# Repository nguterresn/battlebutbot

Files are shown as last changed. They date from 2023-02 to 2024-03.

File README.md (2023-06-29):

# BattleButBot: Your Ultimate Antweight Fighting Robot Companion

BattleButBot is a small and powerful robot designed specifically for the Antweight class of robot combat events. With its sleek design, sturdy construction, and advanced control features, BattleButBot is the perfect choice for robot fighting enthusiasts of all skill levels.

## Features

- **Intuitive Web-based Control**: BattleButBot can be easily controlled from any device with a web browser, allowing you to take full control of your robot in real-time.
- **Powerful Motors**: BattleButBot's high-torque motors provide superior performance and speed, allowing your robot to deliver powerful punches and moves.
- **Durable Build**: BattleButBot is built to withstand the toughest battles in Antweight robot combat events. Its rugged construction and impact-resistant design ensure that your robot stays in one piece, no matter how intense the fight gets.
- **Customizable Weapons**: BattleButBot's weapons can be customized to suit your fighting style. With a range of weapons and attachments available, you can build your robot to be the ultimate fighting machine.
- **Easy to Use**: BattleButBot is easy to use and requires no special skills or training. With its intuitive controls and simple setup process, you can start battling right away.

## Clone

Clone the project by running the following command:

```bash
git clone --recurse-submodules -j8 git@github.com:nguterresn/battlebutbot.git
```

The option `-j8` will allow the command to download up to 8 sumodules in parallel. 

## Goal

* Design the skeleton of the battle bot and list all the required hardware components.
* Assemble the battle bot by mounting all the necessary parts.
* Compete in battles to test the performance of the battle bot.
* Iterate and improve the design based on the performance results.
* Profit from your successful battle bot design.

## List of requirements

* **Cheap**: Priced under $50/500kr
* **Weight**: Weighs less than 150 milligrams
* **Acessable**: All parts are easily available
* **Flexible**: Can be controlled over WiFi or using an RF controller
* **Simple**: All hardware components are easy to assemble
* **Portable**: Powered by a lithium battery

## List of hardware:

| Hardware | Qty | Price |
|---|-----|---|
| [N20 Gear Motor 6V 600RPM](https://www.aliexpress.com/item/1005003480074662.html?spm=a2g0o.cart.0.0.66f238dazFIII7&mp=1) | 2 | 90kr  |
| [DollaTek 5PCS DRV8833 1.5A 2-Channel DC Motor Drive Board](https://www.amazon.se/DollaTek-drivbräda-ultra-liten-drivmodul-ingångsspänning/dp/B07ML2RDNY/ref=sr_1_1?crid=39VO6618PX6XD&keywords=DRV8833&qid=1667334481&qu=eyJxc2MiOiIyLjI4IiwicXNhIjoiMS43NiIsInFzcCI6IjAuOTIifQ%3D%3D&sprefix=drv8833%2Caps%2C115&sr=8-1) | 1 | 17kr  |
| [Wemos D1 Mini ESP8266](https://www.amazon.se/-/en/dp/B01N9RXGHY/ref=twister_B08BY192W7?_encoding=UTF8&psc=1) | 1 | 87kr  |

## Pinout

pinout-diagram

## How to open the GUI

Connect using WiFi to `BattleButBot`.



Open `bot.local` on you browser.



## About the GUI

To control BattleButBot, simply use the **joystick** located in the center of the screen. To configure your joystick settings, click the `⚙️ Config` button.

You can monitor your robot's speed with the speed meter located above the joystick, which displays your robot's speed in meters per second.

Although the **action** button is currently inactive, it will be available in the near future.

For ease of development while the robot firmware is unstable or in development, a console log is located at the bottom of the screen. In the future, an option will be added to hide this log.

## Robot Controls

You can control BattleButBot using the joystick on the graphical user interface (GUI). To move forward, drag the joystick upwards, and to move backward, drag the joystick downwards. The joystick works on an X and Y axis, with Y controlling the speed of the robot and X controlling the direction of movement (left or right).

## Technical Details

(TBA)

## 3rd Party Libraries

- [ESPAsyncWebServer](https://github.com/me-no-dev/ESPAsyncWebServer)
- [Joystick 2](https://github.com/bobboteck/JoyStick)
- [CSS Skeleton Framework](https://skeleton-framework.github.io)

## Tools

- VSCode with PlatformIO
- Fusion360

## Support

If you have any questions or issues with BattleButBot, please contact guterresnogueira@gmail.com. We're always here to help you get the most out of your robot.

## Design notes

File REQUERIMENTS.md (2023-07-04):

This is enough to validate the product and to finish the MVP.

- [ ] Fully 3D printed robot (everything)
  - [ ] PLA/PETG Body
  - [ ] TPU Wheels
- [ ] Easily accessible parts (everyone can buy online)
  - [ ] Battery
  - [ ] Main Controller
  - [ ] Main Driver
  - [ ] Servo
  - [ ] Extra Sensors
- [ ] Option to include a PCB or not (usable with a breadboard as well)
  - [ ] A PCB Requires other modules, makes the robot smarter and ready to battle.
  - [ ] The breadboard option is for development and not meant to be used in battles.
- [ ] Sturdy enclosure (protect around the battery and other electrical components)
- [ ] No need for controller (user can use the phone) but we provide a controller option that is better and ideal for battling.
  - [ ] Phone controller on web (Android or iOS)
  - [ ] RF External Controller (Previous requirements also apply)

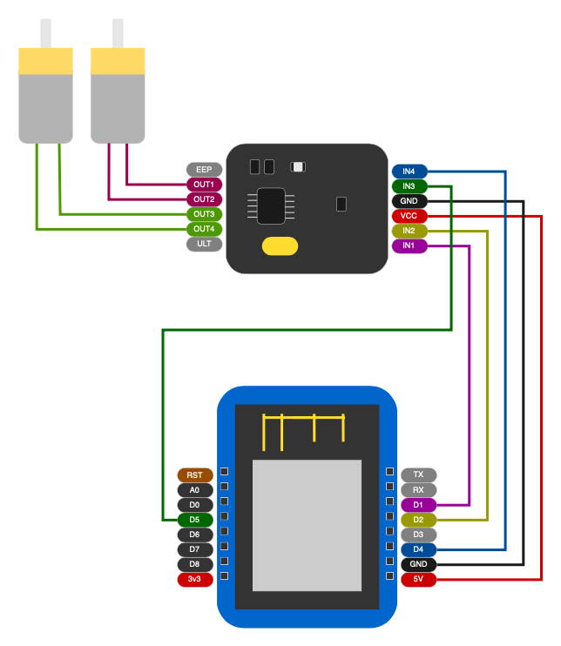
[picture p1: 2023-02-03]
docs/pinout/pinout-diagram.png

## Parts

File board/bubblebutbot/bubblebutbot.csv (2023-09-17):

Comment | Designator | Footprint | LCSC
Buzzer | BZ1 | Buzzer_Beeper:MagneticBuzzer_PUI_AT-0927-TT-6-R | C96256
10u | C1,C2,C3,C9,C10 | Capacitor_SMD:C_0603_1608Metric_Pad1.08x0.95mm_HandSolder | C380316
22u | C12 | Capacitor_SMD:C_1206_3216Metric_Pad1.33x1.80mm_HandSolder | C12891
1u | C4,C5 | Capacitor_SMD:C_0603_1608Metric_Pad1.08x0.95mm_HandSolder | C1592
100n | C6,C8,C11 | Capacitor_SMD:C_0603_1608Metric_Pad1.08x0.95mm_HandSolder | C282519
2.2u | C7 | Capacitor_SMD:C_0603_1608Metric_Pad1.08x0.95mm_HandSolder | C2691406
LED | D1,D3 | LED_SMD:LED_0603_1608Metric_Pad1.05x0.95mm_HandSolder | C965799
SS14 | D2 | Diode_SMD:D_SMA | C2480
MountingHole | H1,H2 | MountingHole:MountingHole_3.2mm_M3_ISO14580_Pad
JST XH | J1,J9,J10,J11,J13 | Connector_JST:JST_PH_S2B-PH-K_1x02_P2.00mm_Horizontal | C722769
USB_C_Receptacle | J2 | Connector_USB:USB_C_Receptacle_GCT_USB4105-xx-A_16P_TopMnt_Horizontal | C2765186
Conn_01x03_Socket | J3,J4,J5,J6,J7,J8 | Connector_JST:JST_PH_S3B-PH-K_1x03_P2.00mm_Horizontal | C10400
4.7u | L1 | Inductor_SMD:L_Wuerth_WE-TPC-3816 | C2879693
FDN336P | Q1 | Package_TO_SOT_SMD:SOT-23 | C475693
5.1K | R1,R2,R3,R4,R6,R7,R9,R10,R12,R13,R17 | Resistor_SMD:R_0603_1608Metric_Pad0.98x0.95mm_HandSolder | C2907114
50k | R11 | Resistor_SMD:R_0603_1608Metric_Pad0.98x0.95mm_HandSolder | C304067
R | R16 | Resistor_SMD:R_0603_1608Metric_Pad0.98x0.95mm_HandSolder | C2930064
3.3k | R5 | Resistor_SMD:R_0603_1608Metric_Pad0.98x0.95mm_HandSolder | C3017726
100k | R8,R14,R15 | Resistor_SMD:R_0603_1608Metric_Pad0.98x0.95mm_HandSolder | C2907088
SW_Push | SW1,SW2 | Button_Switch_SMD:SW_SPST_B3U-1000P | C455280
SW_DIP_x04 | SW3 | Button_Switch_THT:SW_DIP_SPSTx04_Piano_10.8x11.72mm_W7.62mm_P2.54mm | C99418
DRV8833PWP | U1 | Package_SO:HTSSOP-16-1EP_4.4x5mm_P0.65mm_EP3.4x5mm_Mask2.46x2.31mm_ThermalVias | C50506
ESP32-S3-WROOM-1 | U2 | RF_Module:ESP32-S3-WROOM-1 | C2913198
AP2112K-3.3 | U3 | Package_TO_SOT_SMD:SOT-23-5 | C51118
LIS3DH | U4 | Package_LGA:LGA-16_3x3mm_P0.5mm_LayoutBorder3x5y | C15134
~ | U5 | Package_TO_SOT_SMD:SOT-23-8 | C2937216

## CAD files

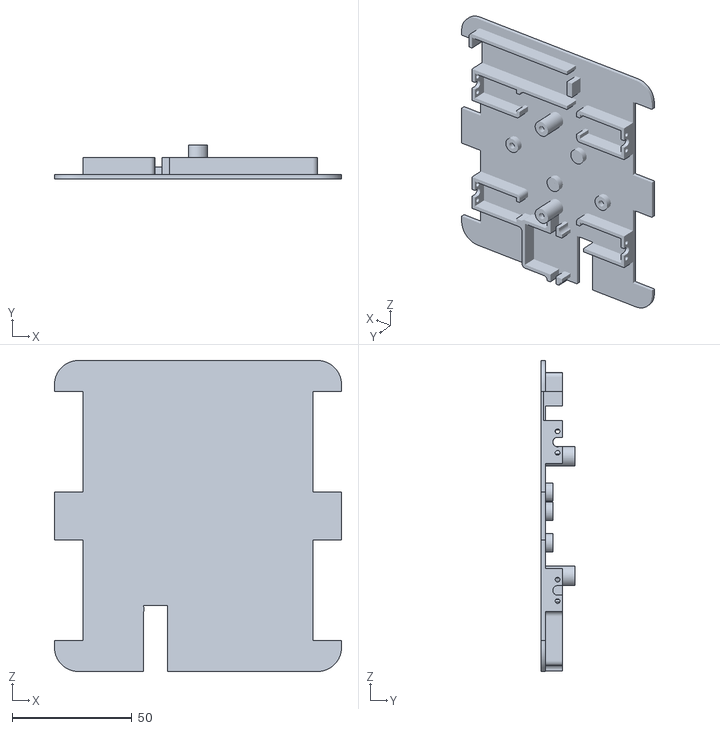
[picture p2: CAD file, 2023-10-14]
board/bubblebutbot/bottom.stl
120.0 x 14.3 x 130.0

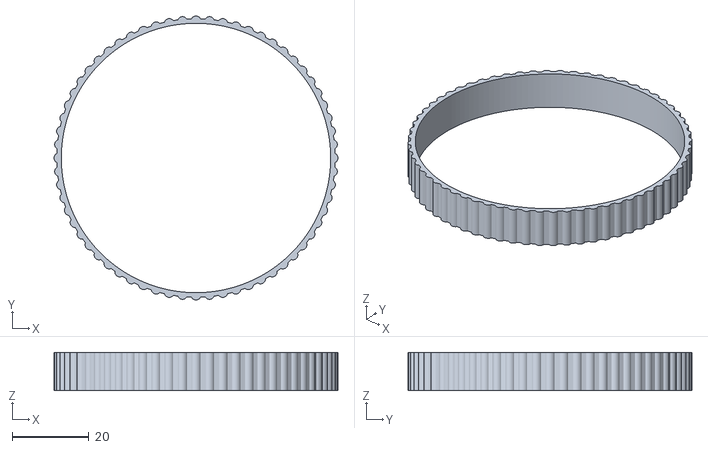
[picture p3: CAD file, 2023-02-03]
body/gustaf/ribbed-belt_v1.stl
73.8 x 73.8 x 10.0

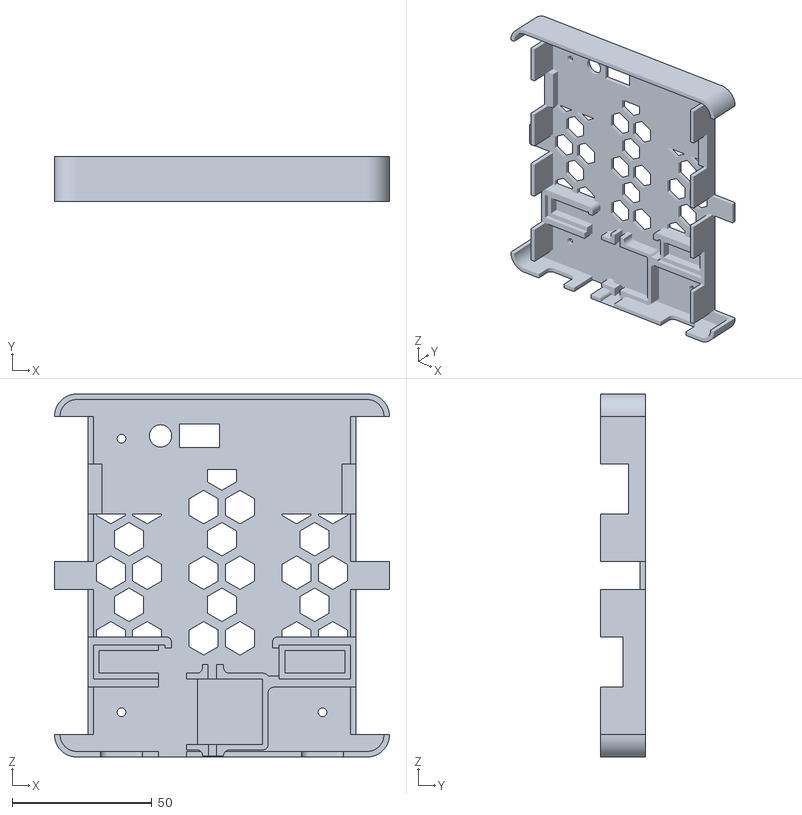
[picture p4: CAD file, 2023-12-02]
body/prod/top.stl
120.0 x 16.0 x 130.0

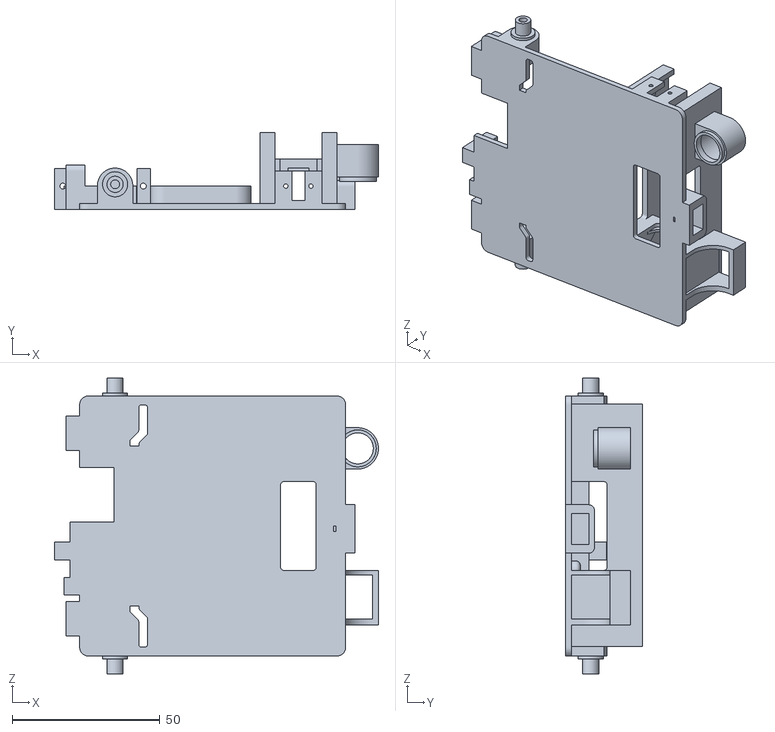
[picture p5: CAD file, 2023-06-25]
body/prototype/Car_with_extras.stl
109.6 x 26.0 x 100.0

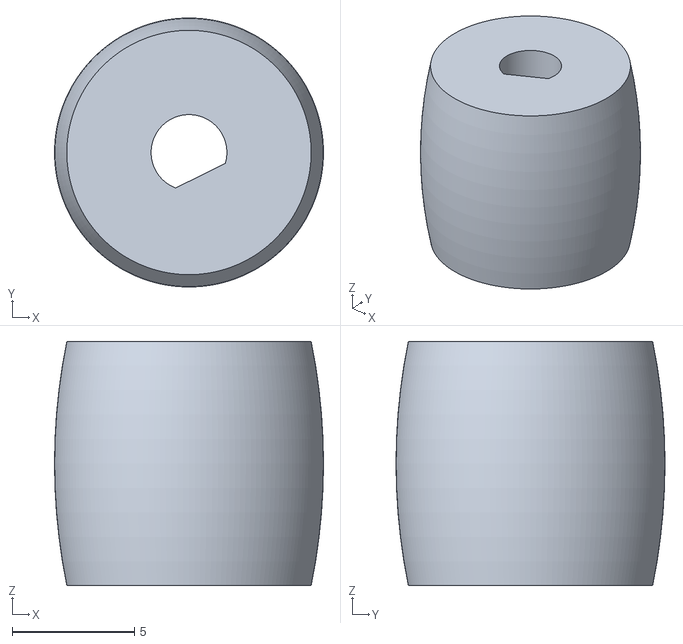
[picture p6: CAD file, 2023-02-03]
body/gustaf/motor-nav_v1.stl
11.0 x 11.0 x 10.0

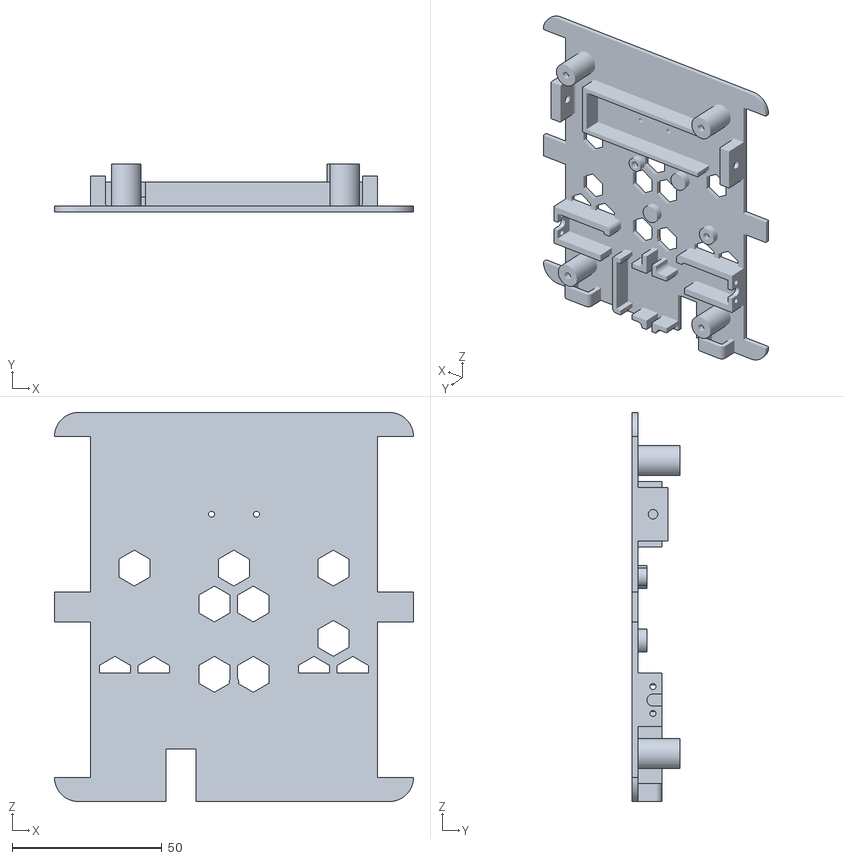
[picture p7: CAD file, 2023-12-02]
body/prod/bot.stl
120.0 x 16.0 x 130.0

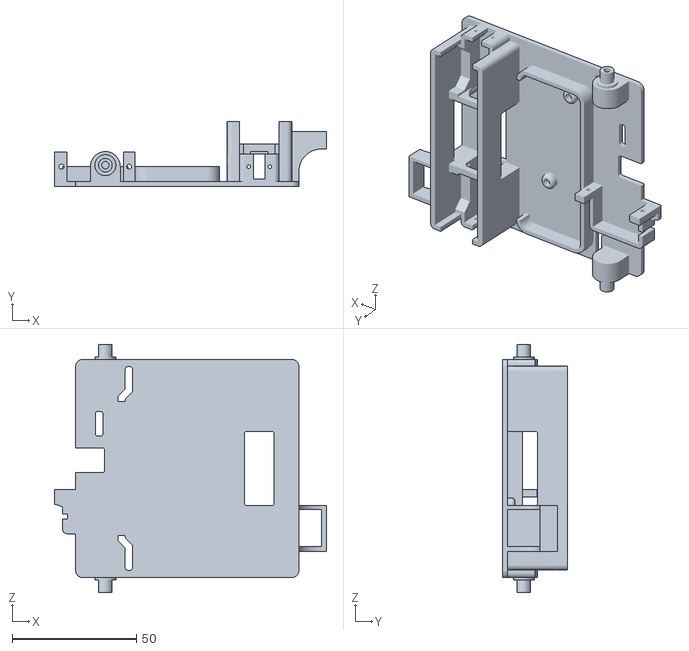
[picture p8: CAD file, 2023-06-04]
body/prototype/Car_with_holders.stl
109.6 x 26.0 x 100.0

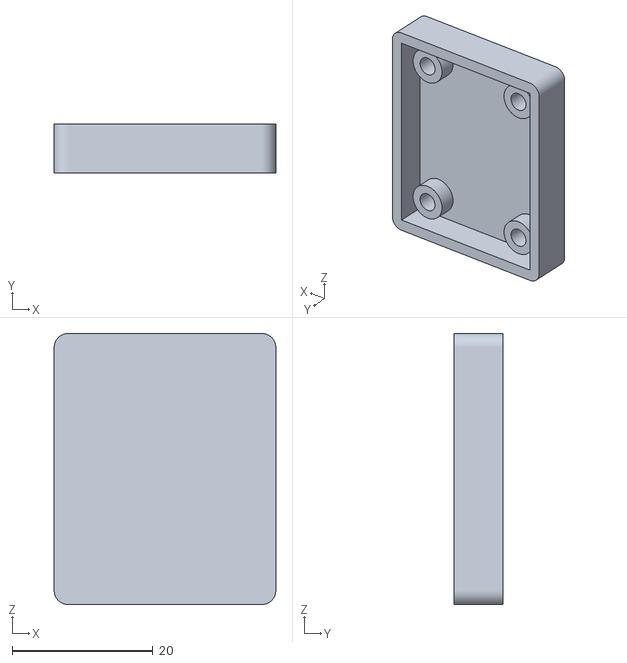
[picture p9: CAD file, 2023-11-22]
body/prod/AnalogControllerBase.stl
31.5 x 7.00 x 38.5

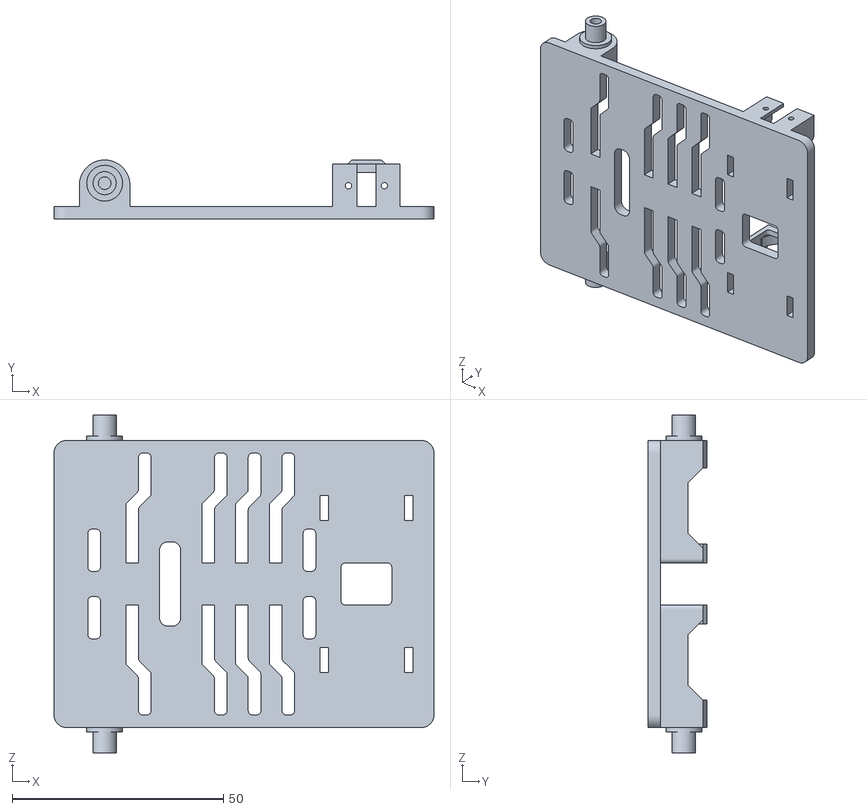
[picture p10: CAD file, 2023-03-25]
body/prototype/Car.stl
90.0 x 14.0 x 80.0

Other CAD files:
body/gustaf/suppoer-nav_v1.stl

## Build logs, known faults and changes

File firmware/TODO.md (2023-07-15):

## TODO

- [x] Add action to GUI without breaking motion.
- [x] Change Joystick value area from a square to a circle (radius = 100).
- [x] Improve GUI responsiveness: prevent sporadic failures.
- [x] Create a small hardware feedback once someone is connected.
- [x] Prevent more than one WiFi connection to the board.
- [x] Adapt and simplify the CSS Skeleton framework for embedded.
- [ ] Verify if the user has the web session open.
- [x] Add config page and add config fields to the EEPROM.
- [x] Update web page according to EEPROM
- [ ] Add Automatic Mode
- [x] Improve Motor's feedback
- [ ] Add support for another wireless protocol
- [ ] Add OTA update support
- [ ] Add support for an accelerometer

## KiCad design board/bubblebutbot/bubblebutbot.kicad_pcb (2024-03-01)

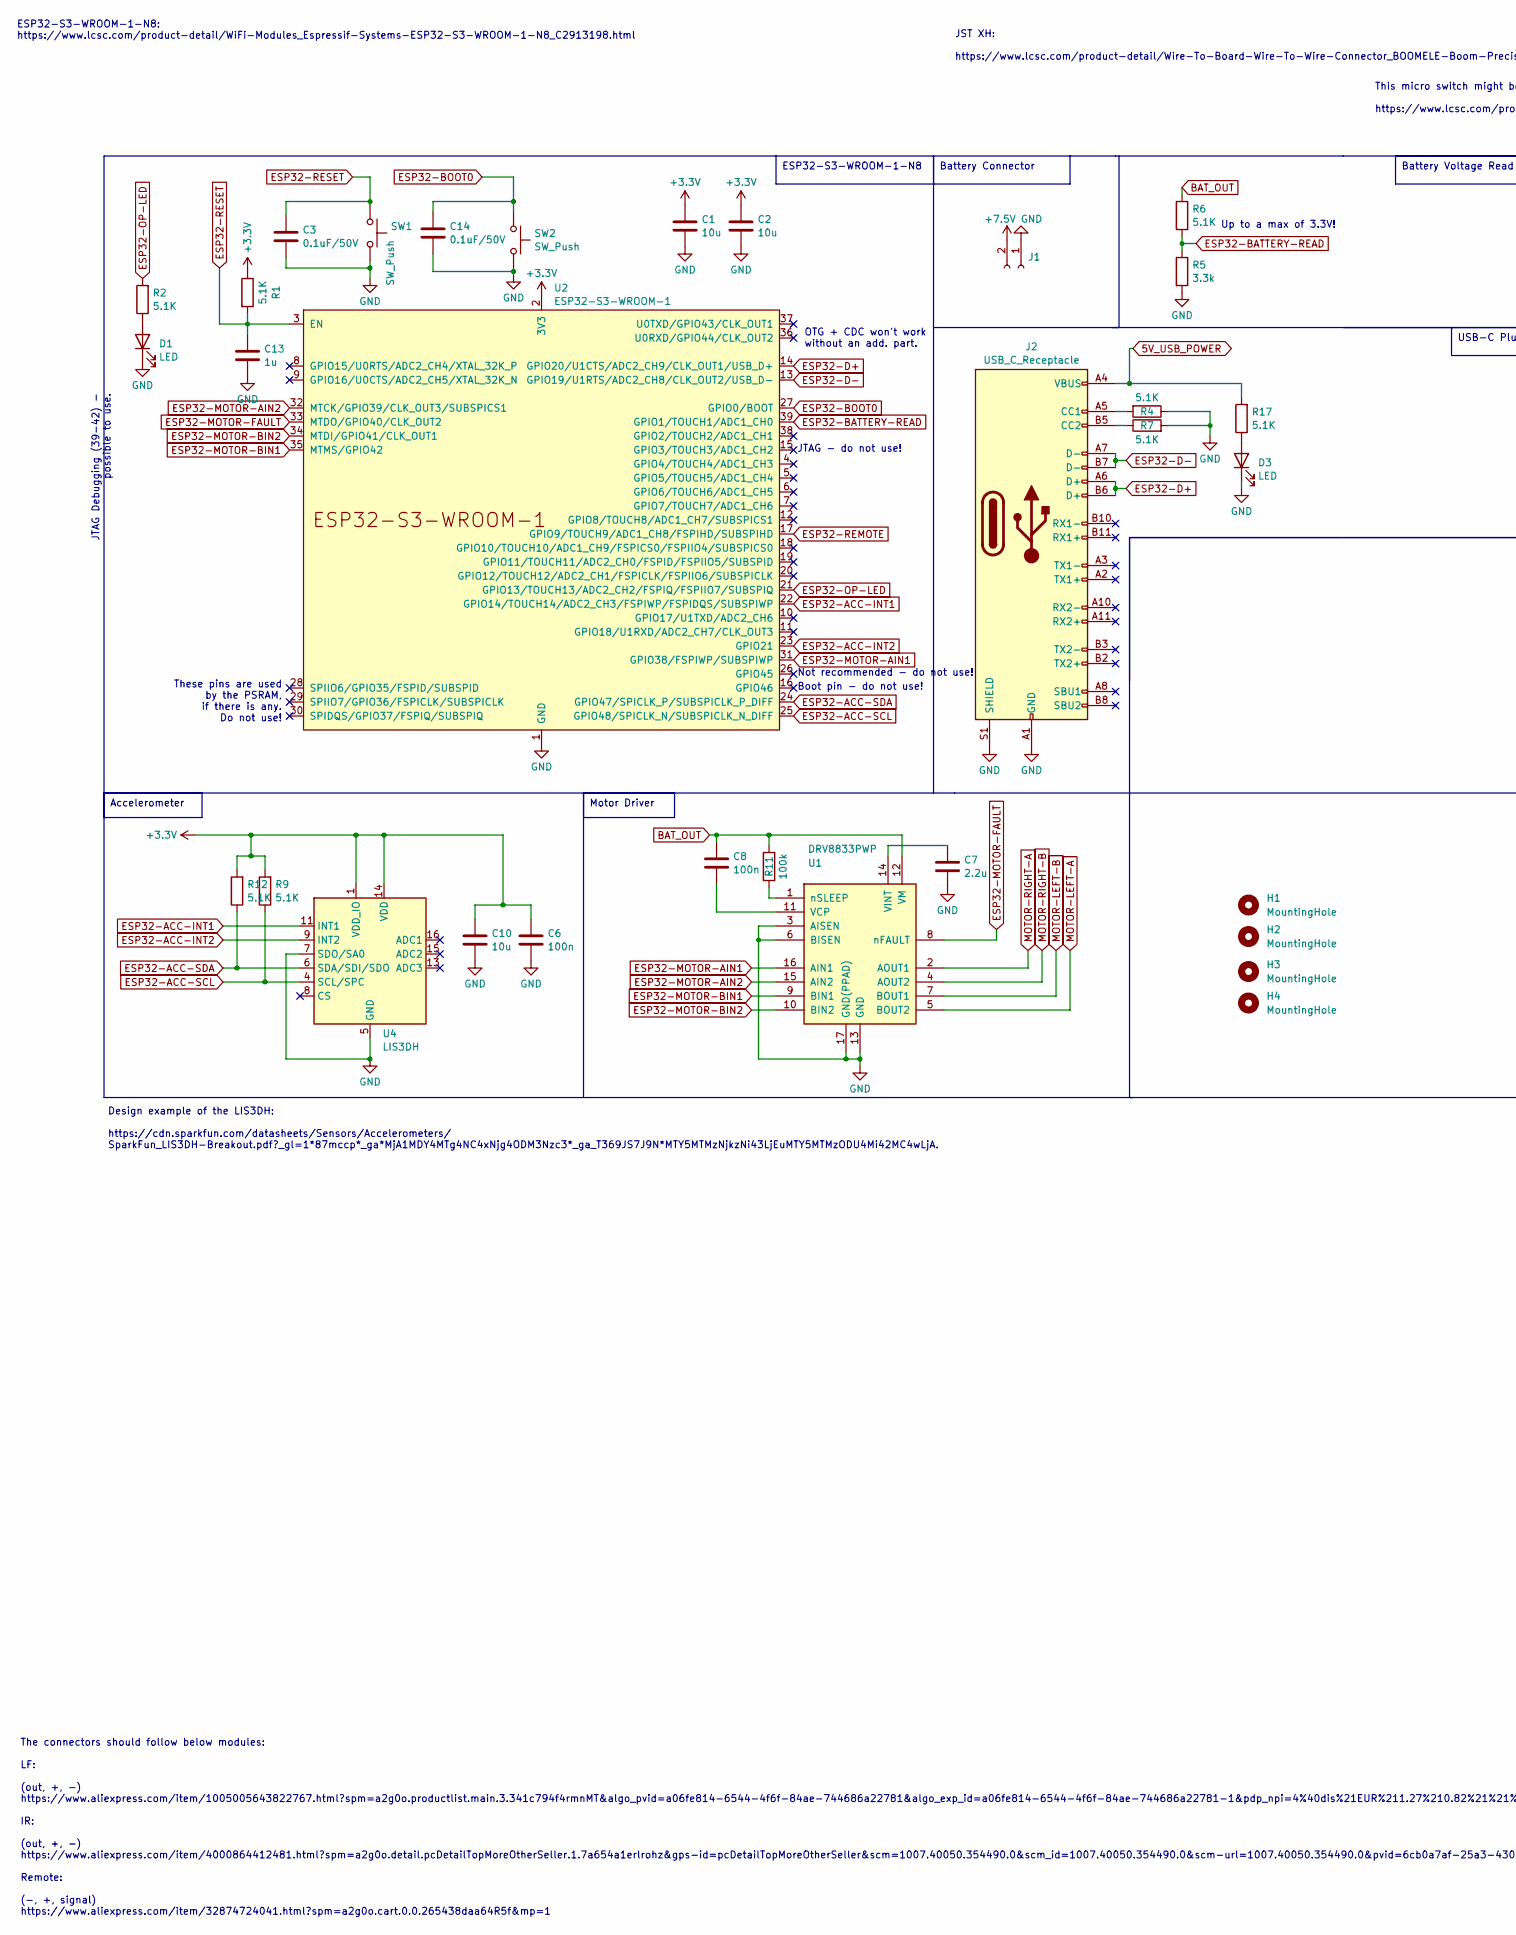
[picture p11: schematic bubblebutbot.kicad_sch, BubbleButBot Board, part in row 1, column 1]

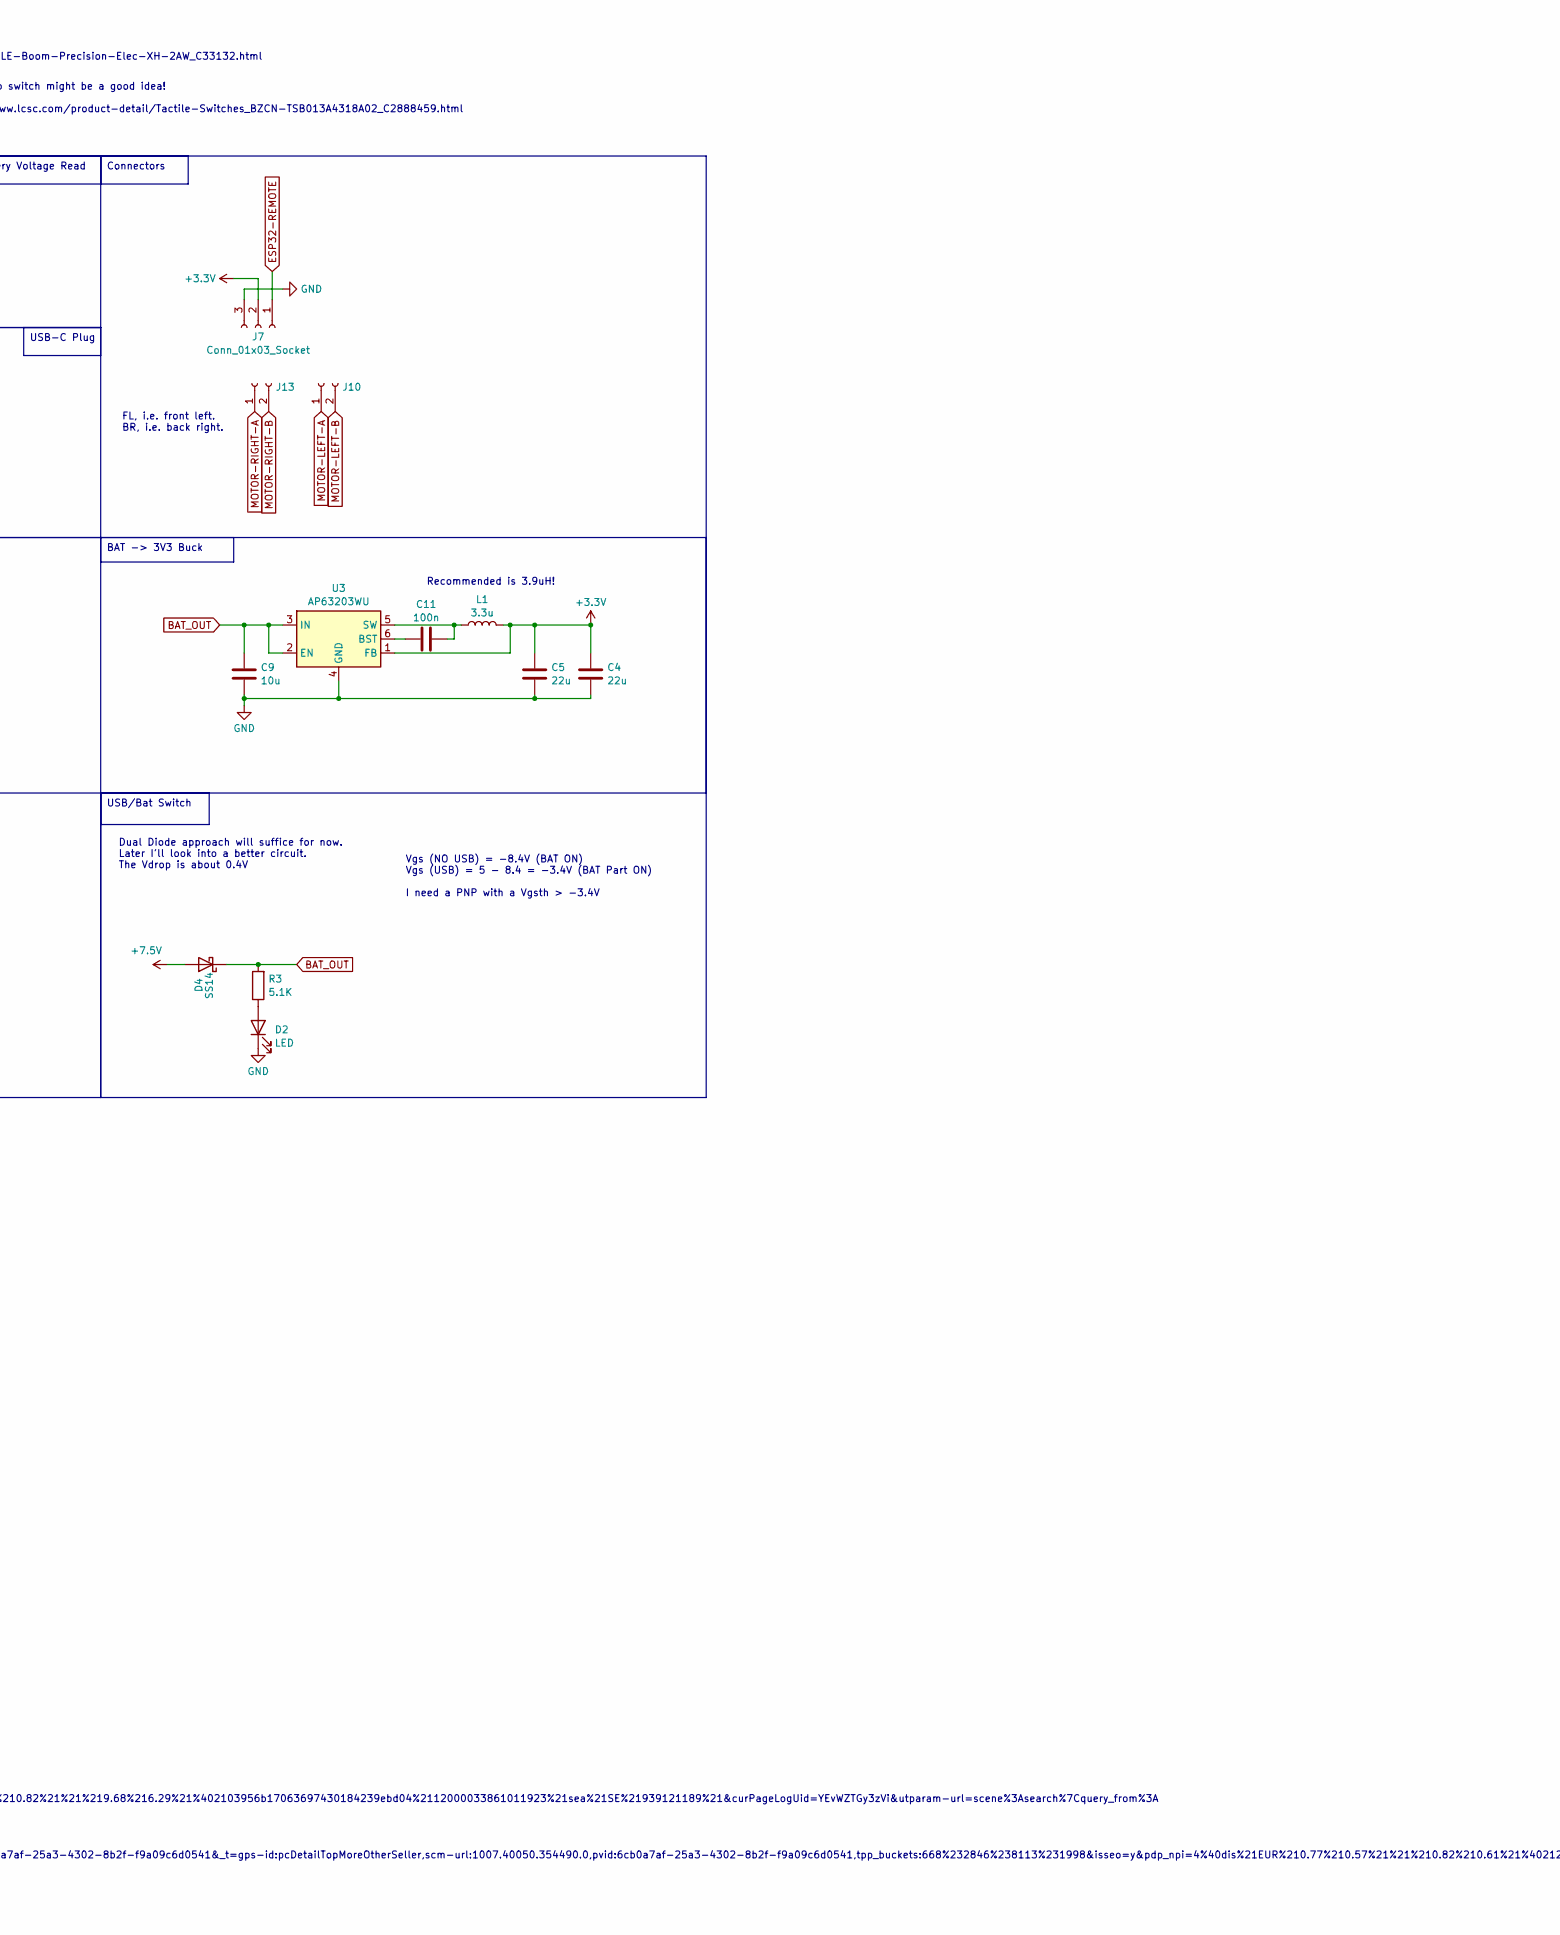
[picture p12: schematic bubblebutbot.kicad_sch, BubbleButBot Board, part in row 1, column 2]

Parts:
C1, C2, C9, C10: 10u; C_0603_1608Metric_Pad1.08x0.95mm_HandSolder; LCSC C380316
C3, C14: 0.1uF/50V; C_0603_1608Metric_Pad1.08x0.95mm_HandSolder
C4, C5: 22u; C_1206_3216Metric_Pad1.33x1.80mm_HandSolder; LCSC C12891
C6, C8, C11: 100n; C_0603_1608Metric_Pad1.08x0.95mm_HandSolder; LCSC C282519
C7: 2.2u; C_0603_1608Metric_Pad1.08x0.95mm_HandSolder; LCSC C2691406
C13: 1u; C_0603_1608Metric_Pad1.08x0.95mm_HandSolder; LCSC C1592
D1, D2, D3: LED; LED_0603_1608Metric_Pad1.05x0.95mm_HandSolder; LCSC C965799
D4: SS14; D_SMA; LCSC C2480
H1, H2, H3, H4: MountingHole; MountingHole_3.2mm_M3_ISO14580_Pad
J1, J10, J13: JST XH; JST_PH_S2B-PH-K_1x02_P2.00mm_Horizontal; LCSC C722769
J2: USB_C_Receptacle; USB_C_Receptacle_GCT_USB4105-xx-A_16P_TopMnt_Horizontal; LCSC C2765186
J7: Conn_01x03_Socket; JST_PH_S3B-PH-K_1x03_P2.00mm_Horizontal; LCSC C10400
L1: 3.3u; L_Wuerth_WE-TPC-3816; LCSC C2929417
R1, R2, R3, R4, R6, R7, R9, R12, R17: 5.1K; R_0603_1608Metric_Pad0.98x0.95mm_HandSolder; LCSC C2907114
R5: 3.3k; R_0603_1608Metric_Pad0.98x0.95mm_HandSolder; LCSC C3017726
R11: 100k; R_0603_1608Metric_Pad0.98x0.95mm_HandSolder; LCSC C2907088
SW1, SW2: SW_Push; SW_SPST_CK_RS282G05A3
U1: DRV8833PWP; HTSSOP-16-1EP_4.4x5mm_P0.65mm_EP3.4x5mm_Mask2.46x2.31mm_The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; LCSC C50506
U2: ESP32-S3-WROOM-1; LCSC C2913198
U3: AP63203WU; TSOT-23-6; LCSC C780769
U4: LIS3DH; LGA-16_3x3mm_P0.5mm_LayoutBorder3x5y; LCSC C15134

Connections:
5V_USB_POWER: J2.A4 (VBUS), J2.A9 (VBUS), J2.B4 (VBUS), J2.B9 (VBUS), R17.2
+3.3V: C1.1, C2.1, C4.1, C5.1, C6.1, C10.1, J7.2, L1.2, R1.1, R9.2, R12.2, U2.2 (3V3), U3.1 (FB), U4.1 (VDD_IO), U4.14 (VDD)
+7.5V: D4.2 (A), J1.2
BAT_OUT: C8.2, C9.1, D4.1 (K), R3.2, R6.2, R11.2, U1.12 (VM), U3.2 (EN), U3.3 (IN)
ESP32-ACC-INT1: U2.22 (GPIO14/TOUCH14/ADC2_CH3/FSPIWP/FSPIDQS/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), U4.11 (INT1)
ESP32-ACC-INT2: U2.23 (GPIO21), U4.9 (INT2)
ESP32-ACC-SCL: R9.1, U2.25 (GPIO48/SPICLK_N/SUBSPICLK_N_DIFF), U4.4 (SCL/SPC)
ESP32-ACC-SDA: R12.1, U2.24 (GPIO47/SPICLK_P/SUBSPICLK_P_DIFF), U4.6 (SDA/SDI/SDO)
ESP32-BATTERY-READ: R5.1, R6.1, U2.39 (GPIO1/TOUCH1/ADC1_CH0)
ESP32-BOOT0: C14.1, SW2.1, U2.27 (GPIO0/BOOT)
ESP32-D+: J2.A6 (D+), J2.B6 (D+), U2.14 (GPIO20/U1CTS/ADC2_CH9/CLK_OUT1/USB_D+)
ESP32-D-: J2.A7 (D-), J2.B7 (D-), U2.13 (GPIO19/U1RTS/ADC2_CH8/CLK_OUT2/USB_D-)
ESP32-MOTOR-AIN1: U1.16 (AIN1), U2.31 (GPIO38/FSPIWP/SUBSPIWP)
ESP32-MOTOR-AIN2: U1.15 (AIN2), U2.32 (MTCK/GPIO39/CLK_OUT3/SUBSPICS1)
ESP32-MOTOR-BIN1: U1.9 (BIN1), U2.35 (MTMS/GPIO42)
ESP32-MOTOR-BIN2: U1.10 (BIN2), U2.34 (MTDI/GPIO41/CLK_OUT1)
ESP32-MOTOR-FAULT: U1.8 (nFAULT), U2.33 (MTDO/GPIO40/CLK_OUT2)
ESP32-OP-LED: R2.2, U2.21 (GPIO13/TOUCH13/ADC2_CH2/FSPIQ/FSPIIO7/S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)
ESP32-REMOTE: J7.1, U2.17 (GPIO9/TOUCH9/ADC1_CH8/FSPIHD/SUBSPIHD)
ESP32-RESET: C3.1, C13.1, R1.2, SW1.1, U2.3 (EN)
GND: C1.2, C2.2, C3.2, C4.2, C5.2, C6.2, C7.2, C9.2, C10.2, C13.2, C14.2, D1.1 (K), D2.1 (K), D3.1 (K), J1.1, J2.A1 (GND), J2.A12 (GND), J2.B1 (GND), J2.B12 (GND), J2.S1 (SHIELD), J7.3, R4.1, R5.2, R7.2, SW1.2, SW2.2, U1.3 (AISEN), U1.6 (BISEN), U1.13 (GND), U1.17 (GND(PPAD)), U2.1 (GND), U2.40 (GND), U2.41 (GND), U3.4 (GND), U4.5 (GND), U4.7 (SDO/SA0), U4.10 (GND), U4.12 (GND)
MOTOR-LEFT-A: J10.1, U1.5 (BOUT2)
MOTOR-LEFT-B: J10.2, U1.7 (BOUT1)
MOTOR-RIGHT-A: J13.1, U1.2 (AOUT1)
MOTOR-RIGHT-B: J13.2, U1.4 (AOUT2)
unnamed: D1.2 (A), R2.1
unnamed: D2.2 (A), R3.1
unnamed: D3.2 (A), R17.1
unnamed: J2.A5 (CC1), R4.2
unnamed: J2.B5 (CC2), R7.1
unnamed: C8.1, U1.11 (VCP)
unnamed: C7.1, U1.14 (VINT)
unnamed: R11.1, U1.1 (nSLEEP)
unnamed: C11.2, U3.6 (BST)
unnamed: C11.1, L1.1, U3.5 (SW)

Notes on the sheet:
Battery Voltage Read
Accelerometer
Battery Connector
USB-C Plug
BAT -> 3V3 Buck
USB/Bat Switch
Connectors
Motor Driver
ESP32-S3-WROOM-1-N8
ESP32-S3-WROOM-1-N8: https://www.lcsc.com/product-detail/WiFi-Modules_Espressif-Systems-ESP32-S3-WROOM-1-N8_C2913198.html
This micro switch might be a good idea! https://www.lcsc.com/product-detail/Tactile-Switches_BZCN-TSB013A4318A02_C2888459.html
Up to a max of 3.3V!
Vgs (NO USB) = -8.4V (BAT ON) Vgs (USB) = 5 - 8.4 = -3.4V (BAT Part ON) I need a PNP with a Vgsth > -3.4V
Design example of the LIS3DH: https://cdn.sparkfun.com/datasheets/Sensors/Accelerometers/ SparkFun_LIS3DH-Breakout.pdf?_gl=1*87mccp*_ga*MjA1MDY4MTg4NC4xNjg4ODM3Nzc3*_ga_T369JS7J9N*MTY5MTMzNjkzNi43LjEuMTY5MTMzODU4Mi42MC4wLjA.
JTAG Debugging (39-42) - possible to use.
JST XH: https://www.lcsc.com/product-detail/Wire-To-Board-Wire-To-Wire-Connector_BOOMELE-Boom-Precision-Elec-XH-2AW_C33132.html
JTAG - do not use!
Dual Diode approach will suffice for now. Later I'll look into a better circuit. The Vdrop is about 0.4V
OTG + CDC won't work without an add. part.
The connectors should follow below modules: LF: (out, +, -) https://www.aliexpress.com/item/1005005643822767.html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…
Boot pin - do not use!
FL, i.e. front left. BR, i.e. back right.
These pins are used by the PSRAM, if there is any. Do not use!
Recommended is 3.9uH!
Not recommended - do not use!

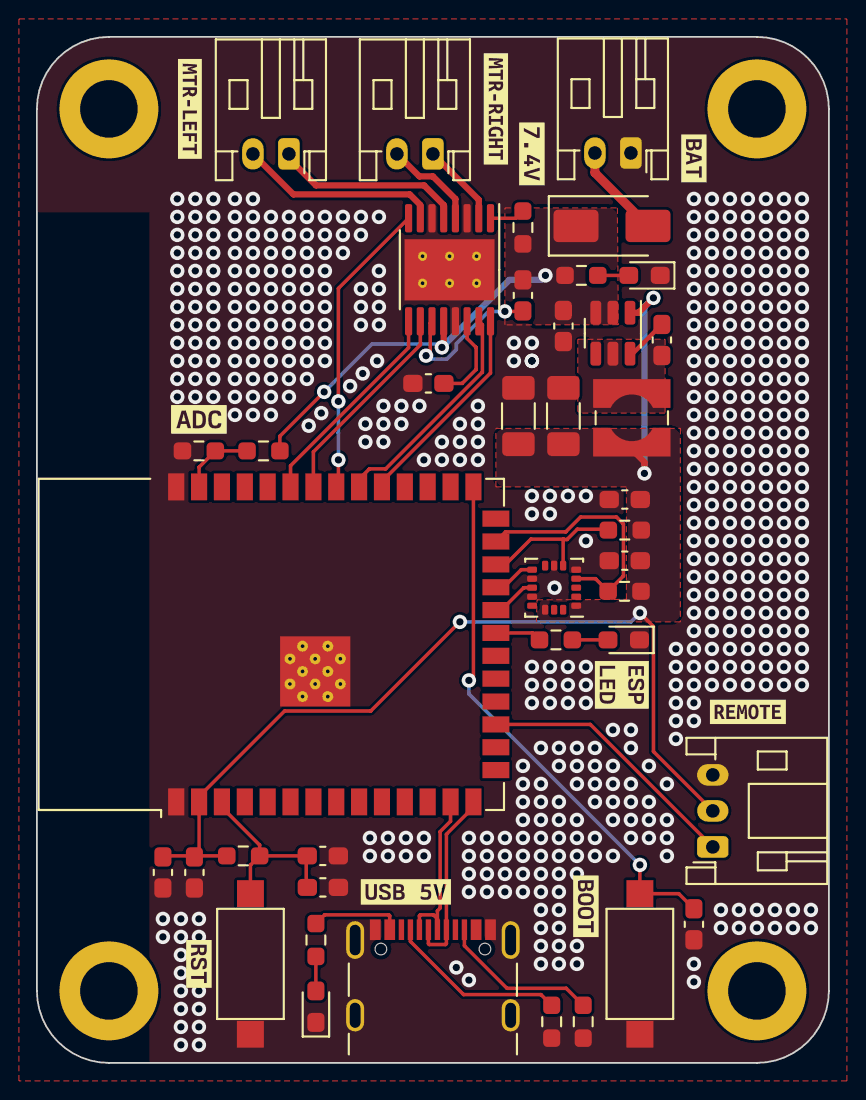
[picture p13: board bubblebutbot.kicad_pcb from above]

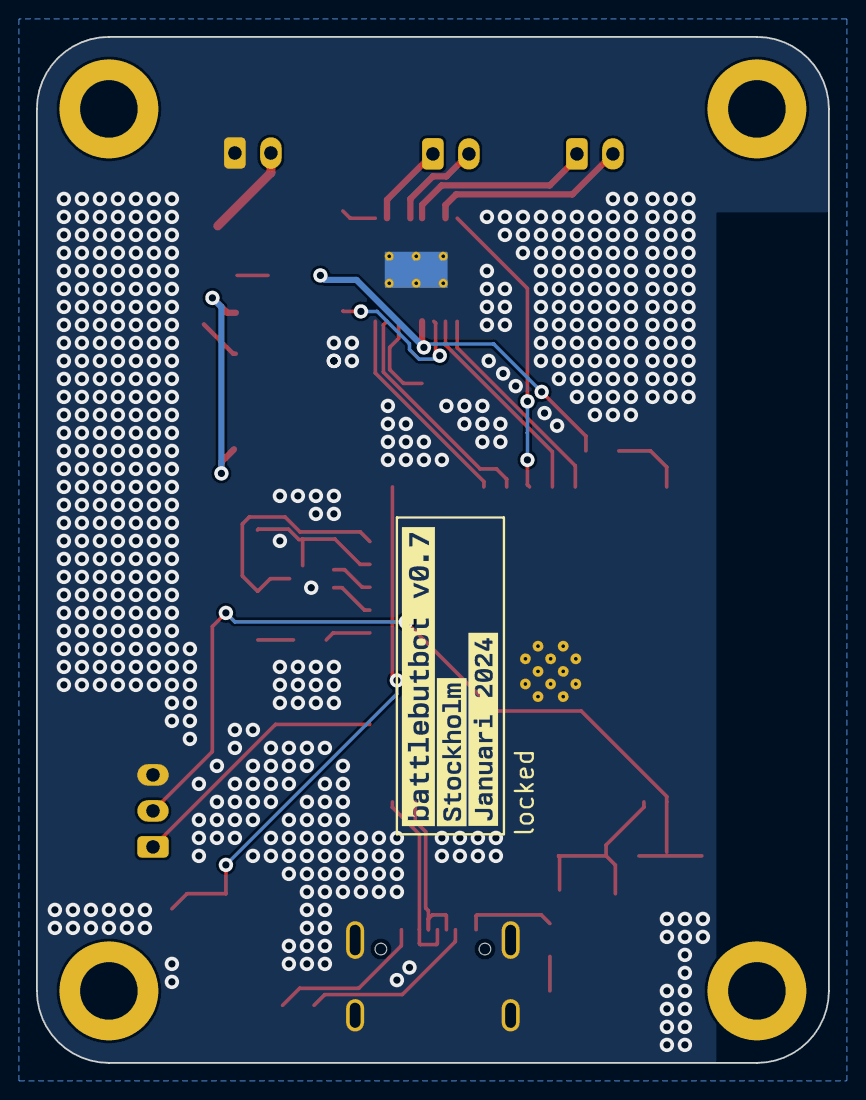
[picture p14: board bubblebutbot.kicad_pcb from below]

Board: 2 copper layers, 44.0 x 57.0 mm, 57 parts (3 on the bottom side), 35 nets.

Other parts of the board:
kibuzzard-65B53DEB: G***; kibuzzard-65B53DEB
kibuzzard-65B53F64: G***; kibuzzard-65B53F64
kibuzzard-65B521AC: G***; kibuzzard-65B521AC
kibuzzard-65B534AD: G***; kibuzzard-65B534AD
kibuzzard-65B534B8: G***; kibuzzard-65B534B8
kibuzzard-65B5357F: G***; kibuzzard-65B5357F
kibuzzard-65B5507C: G***; kibuzzard-65B5507C
kibuzzard-65B52192: G***; kibuzzard-65B52192
kibuzzard-65B53096: G***; kibuzzard-65B53096
kibuzzard-65B53492: G***; kibuzzard-65B53492
kibuzzard-65B53575: G***; kibuzzard-65B53575
kibuzzard-65BE7DA5: G***; kibuzzard-65BE7DA5
kibuzzard-65BE89A1: G***; kibuzzard-65BE89A1

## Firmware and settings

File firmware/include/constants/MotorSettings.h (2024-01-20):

#ifndef MOTOR_SETTINGS_H_
#define MOTOR_SETTINGS_H_

#include <math.h>

#define MOTOR_PWM_FREQUENCY   5000 // 500Hz
#define MOTOR_PWM_RESOLUTION  8    // 8 bits
#define MOTOR_PWM_RANGE       pow(2, MOTOR_PWM_RESOLUTION) - 1

#define MOTOR_RIGHT1_CHANNEL  4
#define MOTOR_RIGHT2_CHANNEL  5
#define MOTOR_LEFT1_CHANNEL   6
#define MOTOR_LEFT2_CHANNEL   7

#define MOTOR_DRIFT_MIN_INPUT 50
#define MOTOR_DRIFT_DEFAULT   100
#define MOTOR_DRIFT_MAX_INPUT 150

#define MOTOR_SPEED_DEFAULT   MOTOR_PWM_RANGE       // Descending speed (255 -> 1)

#endif /* MOTOR_SETTINGS_H_ */

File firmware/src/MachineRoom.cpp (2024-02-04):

#include "MachineRoom.h"
#include "freertos/FreeRTOS.h"
#include "freertos/task.h"
#include "models/ServoMotor.h"
#include "models/ProximitySensor.h"

#define ACCELERATION 5 // The higher the 'faster'

// Configuration cache
settings_t robot_settings;
static struct axis axis;
static uint8_t mode;

// FreeRTOS mutex
static SemaphoreHandle_t mutex;

// Models (class based)
static Motor left(MOTOR_LEFT1, MOTOR_LEFT2, MOTOR_LEFT1_CHANNEL, MOTOR_LEFT2_CHANNEL);
static Motor right(MOTOR_RIGHT1, MOTOR_RIGHT2, MOTOR_RIGHT1_CHANNEL, MOTOR_RIGHT2_CHANNEL);

// Private Functions
static void machine_room_forward(uint8_t pwm);
static void machine_room_backward(uint8_t pwm);
static void machine_room_brake(void);
static void machine_room_loop(void* v);

void machine_room_init(void)
{
	pinMode(FEEDBACK_LED, OUTPUT);

	machine_room_brake();
	BaseType_t result = xTaskCreate(machine_room_loop,
	                                "machine_room_loop",
	                                4096,
	                                NULL,
	                                tskIDLE_PRIORITY,
	                                NULL);

	mutex = xSemaphoreCreateMutex();
	if (mutex == NULL || result != pdPASS) {
		configASSERT(0);
	}
}

static void machine_room_loop(void* v)
{
	(void)v;
	uint8_t target_pwm = 0, target_compensation_pwm = 0;
	int x = 0, y = 0;

	for (;;) {
		if (xSemaphoreTake(mutex, 0)) {
			// !! Critical section !!
			x                       = axis.x;
			y                       = axis.y;
			target_pwm              = axis.target_pwm;
			target_compensation_pwm = axis.target_compensation_pwm;
			// !! Critical section !!
			xSemaphoreGive(mutex);

			// Speed
			if (axis.current_pwm < target_pwm) {
				axis.current_pwm = min(axis.current_pwm + ACCELERATION, target_pwm);
			}
			else if (axis.current_pwm > target_pwm) {
				axis.current_pwm = max(axis.current_pwm - ACCELERATION, target_pwm);
			}
			// Compensation
			if (axis.current_compensation_pwm < target_compensation_pwm) {
				axis.current_compensation_pwm = min(axis.current_compensation_pwm + ACCELERATION,
				                                    target_compensation_pwm);
			}
			else if (axis.current_compensation_pwm > target_compensation_pwm) {
				axis.current_compensation_pwm = max(axis.current_compensation_pwm - ACCELERATION,
				                                    target_compensation_pwm);
			}

			if ((x == 0 && y == 0) || abs(y) < MOTOR_JOYSTICK_DEAD_ZONE) {
				machine_room_brake();
			}
			else if (abs(x) < MOTOR_JOYSTICK_DEAD_ZONE) {
				y > 0 ?
				machine_room_forward(axis.current_pwm) :
				machine_room_backward(axis.current_pwm);
			}
			else if (x > 0 && y > 0) {
				// 1st quadrant - forward and right.
				right.forward(axis.current_compensation_pwm);
				left.forward(axis.current_pwm);
			}
			else if (x < 0 && y > 0) {
				// 2nd quadrant - forward and left.
				right.forward(axis.current_pwm);
				left.forward(axis.current_compensation_pwm);
			}
			// 3rd & 4th quandrant - backwards.
			else if (x < 0 && y < 0) {
				right.backward(axis.current_pwm);
				left.backward(axis.current_compensation_pwm);
			}
			else if (x > 0 && y < 0) {
				right.backward(axis.current_compensation_pwm);
				left.backward(axis.current_pwm);
			}
			// 3rd
			// right.backward(axis.current_pwm);
			// left.backward(axis.current_compensation_pwm);
			// 4th
			// right.backward(axis.current_compensation_pwm);
			// left.backward(axis.current_pwm);
		}
		vTaskDelay(5 / portTICK_RATE_MS);
	}
}

/**
 * @brief Resets machine room by stopping the motors or returning them to initial position.
 *
 */
void machine_room_reset(void)
{
	machine_room_brake();
}

/**
 * @brief Measure and update motors drift
 *
 * @param drift between 50 and 150
 */
static void machine_room_update_drift(uint8_t drift)
{
	uint8_t rightDrift = MOTOR_DRIFT_DEFAULT;
	uint8_t leftDrift  = MOTOR_DRIFT_DEFAULT;

	if (drift > MOTOR_DRIFT_DEFAULT) {
		// The car should lean towards the right. Increase left motor drift.
		leftDrift = max(MOTOR_DRIFT_MAX_INPUT - drift + MOTOR_DRIFT_MIN_INPUT,
		                MOTOR_DRIFT_MIN_INPUT);
	}
	else if (drift < MOTOR_DRIFT_DEFAULT) {
		// The car should lean towards the left. Increase right motor drift.
		rightDrift = max(drift, MOTOR_DRIFT_MIN_INPUT);
	}

	right.update(rightDrift);
	left.update(leftDrift);
}

/**
 * @brief Whenever the car needs to just go forward
 *
 * @param pwm as an unsigned char from 0 to MOTOR_PWM_RANGE
 */
static void machine_room_forward(uint8_t pwm)
{
	right.forward(pwm);
	left.forward(pwm);
}

/**
 * @brief Whenever the car needs to just go backward
 *
 * @param pwm as an unsigned char from 0 to MOTOR_PWM_RANGE
 */
static void machine_room_backward(uint8_t pwm)
{
	right.backward(pwm);
	left.backward(pwm);
}

/**
 * @brief Whenever the car needs to break
 *
 */
static void machine_room_brake(void)
{
	right.brake();
	left.brake();
}

/**
 * @brief Update motors according to web's joystick incoming data.
 *
 * @param x incoming x axis integer from web's joystick.
 * @param y incoming y axis integer from web's joystick.
 */
void machine_room_update(int x, int y)
{
	if (xSemaphoreTake(mutex, 10)) {
		if (x == axis.x && y == axis.y) {
			xSemaphoreGive(mutex);
			return;
		}

		axis.x = x; // Cache 'x'
		axis.y = y; // Cache 'y'

		// Whenever the joystick returns to zero, stop.
		if (x == 0 && y == 0) {
			axis.target_pwm              = 0;
			axis.target_compensation_pwm = 0;
		}
		else {
			// The Y axis informs us the power we should provide to the motors, whereas
			// the X axis informs us about the direction the car should go.
			double radian     = atan2(abs(y), abs(x));
			uint8_t module    = min(sqrt((double)pow(abs(y), 2) + pow(abs(x), 2)), (double)JOYSTICK_MASK);
			uint8_t pwmModule = module * ((float)robot_settings.speed / 100.00);
			uint8_t pwmY      = pwmModule * sin(radian);

			axis.target_pwm              = pwmModule;
			axis.target_compensation_pwm = pwmY;
		}

		xSemaphoreGive(mutex);
	}
}

/**
 * @brief Change the configuration fields according to its bit value
 *
 * @param settings with the robot settings
 */
void machine_room_change(settings_t* settings)
{
	digitalWrite(FEEDBACK_LED,
	             machine_room_is_feedback_led_enabled(settings->configuration));
	machine_room_update_drift(settings->drift);
}

/**
 * @brief Checks if the feedback led is enable
 *
 * @return bool
 */
bool machine_room_is_feedback_led_enabled(uint8_t configuration)
{
	return configuration & ENABLE_FEEDBACK_LED ? true : false;
}

/**
 * @brief Checks if the servo is enable
 *
 * @return bool
 */
bool machine_room_is_servo_enabled(uint8_t configuration)
{
	return configuration & ENABLE_SERVO ? true : false;
}

/**
 * @brief Checks if the auto mode is enabled
 *
 * @return bool
 */
bool machine_room_is_auto_mode_enabled(uint8_t configuration)
{
	return configuration & ENABLE_AUTO_MODE ? true : false;
}

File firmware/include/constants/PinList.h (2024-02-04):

#ifndef PIN_LIST_H_
#define PIN_LIST_H_

// Pins for the ESP32 S1:
// https://randomnerdtutorials.com/esp32-pinout-reference-gpios/

// List of GPIOs
// Note: ADC2 pins cannot be used when Wi-Fi is used.

#ifdef S1
#define MOTOR_LEFT1    16
#define MOTOR_LEFT2    17
#define MOTOR_RIGHT1   22
#define MOTOR_RIGHT2   23
#elif S2
#error "Motor pins are missing for the ESP32 S2"
#elif S3
#define MOTOR_RIGHT1   11
#define MOTOR_RIGHT2   38
#define MOTOR_LEFT1    10
#define MOTOR_LEFT2    9
#endif
#define MOTOR_FAULT    12

#define BATTERY_SENSOR 1
#define FEEDBACK_LED   13

#define ACC_SDA        47
#define ACC_SCL        48
#define ACC_INT1       14
#define ACC_INT2       21

#endif /* PIN_LIST_H_ */

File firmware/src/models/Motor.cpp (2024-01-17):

#include "models/Motor.h"
#include "constants/MotorSettings.h"

// To improve brushed motors:
// https://learn.adafruit.com/improve-brushed-dc-motor-performance?view=all
/**
 * @brief Construct a new Motor:: Motor object
 *
 * @param xIN1 as a pin
 * @param xIN2 as a pin
 */
Motor::Motor(uint8_t xIN1_pin, uint8_t xIN2_pin, uint8_t xIN1_channel, uint8_t xIN2_channel) :
	xIN1_pin(xIN1_pin), xIN2_pin(xIN2_pin), xIN1_channel(xIN1_channel), xIN2_channel(xIN2_channel)
{
	pinMode(this->xIN1_pin, OUTPUT);
	pinMode(this->xIN2_pin, OUTPUT);

	configASSERT(ledcSetup(xIN1_channel, MOTOR_PWM_FREQUENCY, MOTOR_PWM_RESOLUTION));
	configASSERT(ledcSetup(xIN2_channel, MOTOR_PWM_FREQUENCY, MOTOR_PWM_RESOLUTION));

	ledcAttachPin(this->xIN1_pin, xIN1_channel);
	ledcAttachPin(this->xIN2_pin, xIN2_channel);

	this->brake();

	update(MOTOR_DRIFT_DEFAULT);
}

/**
 * @brief Update motor pwm pins (slow decay)
 *
 * @param xIN1pwm
 * @param xIN2pwm
 */
void Motor::move(uint8_t xIN1pwm, uint8_t xIN2pwm)
{
	ledcWrite(xIN1_channel, xIN1pwm);
	ledcWrite(xIN2_channel, xIN2pwm);
}

/**
 * @brief Update drift ratio. 0.5 means max drift. 1 means no drift.
 *
 * @param drift as a value between 0 and 100.
 */
void Motor::update(uint8_t drift)
{
	this->driftRatio = (float)drift / 100.0;
}

void Motor::brake(void)
{
#if defined(HIGH_PERFORMANCE)
	this->move(MOTOR_PWM_RANGE, MOTOR_PWM_RANGE);
#elif defined(LOW_POWER)
	this->move(0, 0);
#endif
}

/**
 * @brief Motor goes forward based on how big is the pwm argument (slow decay).
 *
 * @param pwm as a 8bit value, 255 is max speed
 */
void Motor::forward(uint8_t pwm)
{
#if defined(HIGH_PERFORMANCE)
	// Serial.print("Motor pwm: ");
	// Serial.println((MOTOR_PWM_RANGE - pwm) * driftRatio);
	this->move(MOTOR_PWM_RANGE, MOTOR_PWM_RANGE - pwm);
#elif defined(LOW_POWER)
	this->move(pwm * driftRatio, 0);
#endif
}

/**
 * @brief Motor goes backwards based on how big is the pwm argument (slow decay).
 *
 * @param pwm as a 8bit value, 255 is max speed
 */
void Motor::backward(uint8_t pwm)
{
#if defined(HIGH_PERFORMANCE)
	// Serial.print("Motor pwm: ");
	// Serial.println((MOTOR_PWM_RANGE - pwm) * driftRatio);
	this->move(MOTOR_PWM_RANGE - pwm, MOTOR_PWM_RANGE);
#elif defined(LOW_POWER)
	this->move(0, pwm * driftRatio);
#endif
}

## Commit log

2022-12-03 Adapted code to support more boards
2022-12-03 Fixed dns for esp8266
    [WebServer.h]
2022-12-03 Driver is ready. needs some tweaking.
2022-12-04 Support for two motors
2022-12-04 Removed action button for now. Motor update still up to improvements.
2022-12-07 A very hacky way of controlling the motors.
2022-12-15 improved motor motion
2022-12-18 Added Doxygen comments to the MachineRoom class, added brake method and simplified /fixed once and for all the motor controller code.
    [MachineRoom.cpp]
2022-12-21 Fixed blank page on consecutive refreshes
    [WebServer.cpp]
2022-12-25 Added action button to the html front page.
    i am going to keep the design like this until I have more resources to put into design/css/html etc. From now on, focusing on hw and 3d design to make this happen.
2022-12-25 Missing id on action button!
2023-01-02 Added the prototype 3d model files
    [Car.stl, MotorWheel.stl, SupportWheel.stl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]
2023-01-03 Lighter car body for the protoype
    [Car.stl]
2023-01-29 added belt and nav v1
    [motor-nav_v1.stl, ribbed-belt_v1.stl, suppoer-nav_v1.stl]
2023-03-12 dev board schematic done. Started design
    [bubblebutbot.kicad_pcb, bubblebutbot.kicad_sch]
2023-03-18 new design for the prototype
    [Car.stl, MotorWheel.stl, SupportWheel.stl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]
2023-03-19 updated designs
    [Car.stl, MotorWheel.stl]
2023-03-19 Added a connect feedback using the motors.
2023-03-19 Reverted the analog pwm value from 100 to 255.
    [MachineRoom.cpp]
2023-03-24 Update designs. Minor changes
    [Car.stl, SupportWheel.stl]
2023-03-25 Finished prototype pcb
    [Car.stl, SupportWheel.stl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]
2023-03-25 ignore kicad cache
2023-03-25 added bigger wheels
    [MotorWheel.stl, SupportWheel.stl]
2023-03-25 Moved BOM files into a new folder.
    [bubblebutbot.csv]
2023-03-26 Added config page. proper design, logic and memory management missing.
    [WebServer.cpp, WebServer.h]
2023-04-02 redesigned the home page with flexbox and a minimal css framework, a mix between the skeleton and a grid system. Css file is not external
    [WebServer.cpp]
2023-04-19 Added a missing inductor to the design
    [bubblebutbot.kicad_pcb]
2023-05-09 gerber for 1v01 ready
    [bubblebutbot.kicad_pcb, bubblebutbot.kicad_sch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]
2023-05-17 pcb step file, new attempt to have a functioning prototype with a battery holder and some code formatting.
    [Car_with_holders.stl]
2023-05-25 New wheels with steps
    [MotorWheel.stl, SupportWheel.stl]
2023-05-26 loading the configuration is possible now. Changing the switches and sliders is the only step left to do.
2023-06-04 Added servo init code.
2023-06-04 Include flip mechanism for the servo
    [MachineRoom.cpp, Robot.cpp, WebServer.cpp]
2023-06-06 New ServoMotor class
2023-06-06 Added battery level to config html page.
2023-06-10 Prevent double tap zoom in the web page. Allow multi-touch actions
    [WebServer.cpp]
2023-06-11 Added method to brake inside Motor class
2023-06-19 Changed Motor control to be with slow decay instead of fast decay
    [ConfigurationFields.h]
2023-06-19 Moved some files into folders
    [ConfigurationFields.h]
2023-06-20 Moved the cnfiguration change to the Machine Room and added a enabled field for the servo
2023-06-20 Added a test to the ServoMotor class.
2023-06-25 Added support for ESP32 and a custom partition for it to use more app memory and less spiffs/ota second bankl
    [Car_with_extras.stl, custom_partition.csv]
2023-06-25 esp32 working on esp-idf and arduino at the same time.
    [custom_partition.csv]
2023-06-27 Added arduino compoenent.
2023-06-28 Added arduino libraries as a components. Rewrote the servo class to use hal libraries.
2023-06-29 Some clean up
    [ConfigurationFields.h]
2023-07-01 Added auto mode
    [ConfigurationFields.h]
2023-07-23 first steps into the final prod pcb!
    [bubblebutbot.kicad_sch]
2023-07-23 added acc and 3v3 buck
    [bubblebutbot.kicad_sch]
2023-07-24 Added some more pins and set up the DIPx4
    [bubblebutbot.kicad_sch]
2023-08-06 A few additions: new acc and motor driver schematics.
    [bubblebutbot.kicad_sch]
2023-08-09 added buck to 5V
    [bubblebutbot.kicad_sch]
2023-08-13 finished schematic and BOM. Design is ready to start!
    [bubblebutbot.csv, bubblebutbot.kicad_pcb, bubblebutbot.kicad_sch]
2023-08-28 a few more improvements here and there. Almost there.
    [bubblebutbot.kicad_pcb, bubblebutbot.kicad_sch]
2023-09-17 pcb done!
    [bubblebutbot.csv, bubblebutbot.kicad_pcb, bubblebutbot.kicad_sch]
2023-10-01 generated new ibom.html
    [bubblebutbot.kicad_pcb]
2023-10-01 Create sdkconfig.esp32-s3-devkitc-1
2023-10-07 support for esp32s3
    [bubblebutbot.kicad_sch]
2023-10-08 first prod body version
    [bottom.stl, top.stl]
2023-10-14 Moved a couple of files over to include/src folders. Removed ledc lib call and addded ESP32Servo lib
    [bottom.stl, top.stl]
2023-10-14 Removed the MachineRoom class and replaced with normal code
    [MachineRoom.cpp, Robot.cpp]
2023-10-14 A few fixes for freeRTOS tasks.
    [MachineRoom.cpp, Robot.cpp]
2023-11-04 a few comments
    [bubblebutbot.kicad_sch]
2023-11-05 brake on start
2023-11-12 Removed Buzzer. Added support for ESP32 ("S1")
    [MachineRoom.cpp, PinList.h, Robot.cpp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]
2023-11-12 pcb 1v04
    [bubblebutbot.kicad_pcb, bubblebutbot.kicad_sch]
2023-11-12 small fix
    [bubblebutbot.kicad_pcb]
2023-11-20 new testing prod designs
    [bot.stl, bottom.stl, top.stl]
2023-11-22 Added as drift slider
    [WebServer.cpp, WebServer.h]
2023-11-22 drift from float to int
    [ConfigurationFields.h]
2023-11-22 Redundant way of storing the drift value
    [MachineRoom.cpp, Robot.cpp]
2023-11-22 Revert "Added as drift slider"
    This reverts commit 1904178970575699550478b9d1a593eb7e742978.
    [WebServer.cpp, WebServer.h]
2023-11-25 simplified the handle of the configuration
    [ConfigurationFields.h]
2023-11-25 Preparing for trouble 😈
2023-11-25 Drift Ratio to Motor!
    [Motor.cpp]
2023-11-25 Solidify the drift ratio logic
    [MachineRoom.cpp, Motor.cpp]
2023-11-26 Fixed EEPROM
    [ConfigurationFields.h]
2023-11-26 Fixed small bug on config.html
    [Robot.cpp]
2023-12-02 pcb v0.5
    smaller
    [bubblebutbot.kicad_pcb, bubblebutbot.kicad_sch]
2023-12-02 new prod deisgn
    [bot.stl, top.stl]
2024-01-04 gerber prod 1v05
2024-01-14 Fixed speed config step
    [MachineRoom.cpp]
2024-01-14 Drift is still not working. A few other fixes and comments!
    [Motor.cpp]
2024-01-16 theres a bug when the car drives backwards
    [MachineRoom.cpp, Motor.cpp]
2024-01-17 replaced arduino analogWrite by ledC arduino wrapper
    [MachineRoom.cpp, Motor.cpp, MotorSettings.h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]
2024-01-24 v2.06 schamtic
    [bubblebutbot.kicad_sch]
2024-01-25 Working on the new version ... 🚀
    [bubblebutbot.kicad_pcb, bubblebutbot.kicad_sch]
2024-01-27 VERSION 1.06
    [bubblebutbot.kicad_pcb, bubblebutbot.kicad_sch]
2024-01-28 added new v06 step
    [bubblebutbot.kicad_pcb]
2024-02-03 prod 1v7
    [bubblebutbot.kicad_pcb, bubblebutbot.kicad_sch]
2024-03-01 Better UI
    [MotorWheel.stl, SupportWheel.stl, bubblebutbot.kicad_pcb]
